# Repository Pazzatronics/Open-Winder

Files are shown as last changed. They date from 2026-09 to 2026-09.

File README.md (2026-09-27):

# Open Winder

A DIY guitar pickup coil winder built around a Teensy 4.1: standalone touchscreen operation (planned), tension feedback via load cell, EEPROM/flash profile storage, and wind logging.

This repo is open source. Ready-made/printed components based on this design are also sold separately by [Pazzatronics](https://www.pazzatronics.com) — building it yourself from these files is always free and unrestricted under the terms below.

## Repo layout

```
firmware/       Teensy 4.1 sketch and any supporting libraries
hardware/
  fusion360/    Native Fusion 360 project files
  stl/          Print-ready STL files (all parts printed in PETG)
  step/         Exported STEP files (winder body, brackets, load-cell pulley, etc.)
  wiring/       Pinout tables, wiring notes, and open_winder_wiring.csv
  bom.md        Bill of materials with sourcing links
docs/           Bug write-ups, firmware architecture notes, command protocol
```

## Hardware stack

| Part | Component |
|---|---|
| MCU | Teensy 4.1 (3.3 V logic) |
| Stepper driver | DM542T |
| Winder motor | 23HS45-4204S (4.2 A, 3 Nm) |
| PSU | LRS-350-24 (24 V) |
| Load cell | HX711 amplifier + parallel-beam 1 kg load cell |
| Flash storage | Winbond W25Q64JV (QSPI, LittleFS) |
| Level shifting | 74AHCT125 (Teensy 3.3 V → driver 5 V logic) |

Full sourcing and links: [`hardware/bom.md`](hardware/bom.md)

## Status

This is an active, evolving hobby project — see [`docs/bugs-and-fixes.md`](docs/bugs-and-fixes.md) for known firmware issues and their fix status, and [`docs/rebuild-architecture.md`](docs/rebuild-architecture.md) for the planned ISR-based firmware rewrite.

## License

- **Firmware** (`firmware/`): [MIT](LICENSE-FIRMWARE) — do whatever you want with it, attribution appreciated.
- **Hardware** (`hardware/`): [CERN-OHL-S v2](LICENSE-HARDWARE) — you're free to build, modify, and even sell things made from these designs, but if you distribute a modified version of the hardware design itself, you need to share those modifications under the same license.

Questions about licensing or commercial use beyond what these licenses already allow: open an issue or reach out directly.

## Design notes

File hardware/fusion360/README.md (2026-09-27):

# Fusion 360 Files

Native Fusion 360 project files for the Open Winder assembly go here (.f3d exports, or a note pointing to the hosted Fusion 360 project if you'd rather link than commit binary CAD files directly).

Current assembly includes:
- Winder body/frame
- Load cell pulley (three-wheel over/under/over routing, 30° strand angle, 1:1 force ratio)
- Laser module mount (Ø9 x 33 mm housing, emitting face at world origin, beam along +Z)

See ../step/ for exported STEP files if you want a CAD-tool-agnostic format alongside the native files.

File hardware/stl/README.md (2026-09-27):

# Open Winder STL Files

Print-ready STLs for the Open Winder body, clamps, motor brackets, limit-switch housings and tension-sensor housing.

All parts are printed in **PETG**.

| File | Part |
|---|---|
| Housing_1.stl | Main housing |
| Top_Clamp_1.stl / Bottom_Clamp_1.stl | Clamps |
| Motor_Bracket_Front_Top_Spindle_1.stl / Motor_Bracket_Rear_Top_Spindle_1.stl | Spindle (winder) motor brackets |
| Motor_Bracket_Front_Top_Traverse_1.stl / Motor_Bracket_Rear_Top_Traverse_1.stl | Traverse motor brackets |
| Top_Limit_Housing_1.stl / Bottom_Limit_Housing_1.stl | Limit-switch housings |
| Tension_Sensor_Housing_1.stl | Load-cell (tension sensor) housing |

Editable CAD is in `../step/` (STEP) and `../fusion360/` (Fusion 360).

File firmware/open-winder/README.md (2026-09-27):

# Open Winder Firmware

Target: Teensy 4.1, built with Arduino IDE + Teensyduino.

`open_winder_public.ino` is the current public firmware (based on rev 2026-09-16b).

## Before your first run

- Set `TRAV_LEAD_UM_PER_REV` to your traverse lead screw (in microns per revolution).
- Set `WINDER_STEPS_PER_REV` and `TRAV_STEPS_PER_REV` to match the DM542T DIP switches on each drive (the defaults assume 400 steps/rev: SW5 OFF, SW6 ON, SW7 ON, SW8 ON).
- The `defcal` window constants (`DEFAULT_PROFILE_*`, `DEFAULT_CAL_OFF*`) came from the reference machine. Run `cal`, set your bounds with `jogt`/`jogb`/`savet`/`saveb`, send `donecal`, then `stat`, and copy `DEF_TOP_INSET_STEPS` / `DEF_BOTTOM_INSET_STEPS` into the sketch.

## Running a wind

Commands are typed over USB serial at 115200 baud. Send `help` for the full list. A minimal job:

```
dir cw
rpm 500
turns 8000
space 1.0
defcal
start
```

Wiring for every pin used here is in `../../hardware/wiring/open_winder_wiring.csv`.

See `../../docs/bugs-and-fixes.md` for known issues and `../../docs/rebuild-architecture.md` for the planned ISR-based rewrite.

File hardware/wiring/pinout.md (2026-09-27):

# Pinout & Wiring Notes

Bench-verified on the as-built machine, September 2026.

## Limit switches

| Pin | Function | Notes |
|---|---|---|
| 7 | BOTTOM limit | NC switch: idle LOW, tripped HIGH |
| 8 | TOP limit | NC switch: idle LOW, tripped HIGH |

Traverse direction: **CW = toward TOP** (`TRAVERSE_DIR_INVERT = false` is correct for this build).

## Load cell (HX711)

| Pin | Function |
|---|---|
| 30 | DT (data) |
| 31 | SCK (clock) |

Bit-banged GPIO, not a hardware SPI/I2C peripheral. Originally 22/23 in early firmware — moved to 30/31 in the current build.

## Winder motor coil pairing (23HS45-4204S)

Verified with a multimeter — **do not assume by wire color convention**:

- Coil A: black + green
- Coil B: red + blue

(The usual convention of black/red as one pair and blue/green as the other does **not** hold for this motor.)

## Stepper driver (DM542T)

- DIP switches set for **4.20 A peak**, **1600 microsteps/rev** at the driver
- Bench-verified actual winder motion: 1600 pulses = 4.000 revolutions → **400 steps/rev**, corresponding to microstep setting 2 (SW5 OFF / SW6 ON / SW7 ON / SW8 ON)
- Traverse axis steps/rev not yet verified — its DIP switches differ from the winder axis

## Logic level shifting

Teensy 4.1 I/O is 3.3 V; DM542T STEP/DIR inputs are spec'd 4–5 V. A 74AHCT125 buffer is planned/used on these lines. Hardware margin note: DIR setup time measured at exactly the 5 µs minimum — suspected root cause of traverse drift at direction reversals (see `docs/bugs-and-fixes.md`).

## Safety / interlocks

- Run-permit and snag-fault inputs are **not wired** in the current build
- E-stop is the LRS-350 power switch
- Snag-detection code is retained in firmware behind a compile flag for future use

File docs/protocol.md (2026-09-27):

# Command Protocol

ASCII text protocol over USB serial and Serial1, unchanged across the patched firmware and the planned rebuild.

> **Status:** partial — this file has the commands referenced so far in project notes. Fill in the rest of the command set (full syntax, arguments, and responses) as you formalize it. Consider this a living reference, not a spec written up front.

## Known commands

| Command | Purpose |
|---|---|
| `reset` | Reset run state; preserves tare |
| `resetall` | Full reset — re-seeds ISR timing state, restores motion after a dead-motor freeze |
| `driftcomp <steps> <turns>` | Manually set learned per-reversal traverse drift correction |
| `saveprofile` | Save current profile/preset/tension calibration to EEPROM |

## Reporting

| Report | Trigger |
|---|---|
| `RECAL_DRIFT` | Emitted at every auto-recalibration |
| `STATUS` | Periodic telemetry (target: fixed 10 Hz, gated by `availableForWrite()`) |
| `FAULT_STALL` | Raised when hall-index-derived RPM/turn count disagrees with commanded step count |

## Turn-boundary concepts

- **Chaos** — pattern variation applied to traverse spacing
- **Mid** — mid-point traverse behavior
- **Taps** — intermediate turn-count targets within a wind
- **Total** — final target turn count for the wind

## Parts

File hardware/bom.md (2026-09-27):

# Bill of Materials

Links below are **search queries**, not pinned product listings — sellers, prices, and ASINs on generic electronics parts (steppers, drivers, PSUs) turn over too often for a fixed link to stay reliable. Click through, compare current listings, and confirm specs match the row before buying.

| Qty | Part | Key specs | Source | Notes |
|---|---|---|---|---|
| 1 | Teensy 4.1 | ARM Cortex-M7 @ 600 MHz, 3.3 V logic | **[pjrc.com](https://www.pjrc.com/store/teensy41.html)** (buy direct — see note) | Third-party Amazon listings routinely mark this up over PJRC's own price; PJRC is the manufacturer |
| 1 | Stepper driver | DM542T, 4–5 V input, up to 50 V / 4.2 A | [Amazon search](https://www.amazon.com/s?k=DM542T+stepper+driver) | DIP-configured for 4.20 A peak, 1600 µsteps in this build |
| 1 | Winder motor | NEMA23 stepper, 23HS45-4204S, 4.2 A, 3 Nm, 0.88 Ω, 3.4 mH | [Amazon search](https://www.amazon.com/s?k=23HS45-4204S+nema+23+stepper+motor) | Coil pairing bench-verified: black+green = coil 1, red+blue = coil 2 (not the usual black/red + blue/green convention) |
| 1 | Power supply | LRS-350-24, 24 V rail, 350 W enclosed switching PSU | [Amazon search](https://www.amazon.com/s?k=LRS-350-24+power+supply) | Confirmed 24 V variant (not 36/48 V) |
| 1 | Load cell + amp | HX711 amplifier board + parallel-beam 1 kg load cell | [Amazon search](https://www.amazon.com/s?k=HX711+load+cell+1kg+parallel+beam) | Bit-banged GPIO; pins DT=30, SCK=31 in this build |
| 1 | Flash storage | Winbond W25Q64JV, QSPI NOR flash, 64 Mbit | [Amazon search](https://www.amazon.com/s?k=W25Q64JV+flash+chip) | For wind-log storage via LittleFS |
| 1+ | Level shifter | 74AHCT125, quad buffer/line driver | [Amazon search](https://www.amazon.com/s?k=74AHCT125) | Needed on STEP/DIR lines: Teensy is 3.3 V, DM542T inputs are spec'd 4–5 V |
| — | Limit switches | Mechanical/optical, NC configuration | [Amazon search](https://www.amazon.com/s?k=limit+switch+NC) | Bench-verified: pin 7 = BOTTOM, pin 8 = TOP; idle LOW, tripped HIGH |
| — | Fasteners / misc | — | — | See Fusion 360 assembly BOM export for exact hardware call-outs |

## Not yet finalized

- Touchscreen: leaning ESP32-S3 + capacitive LCD (LVGL over UART) vs. Nextion NX4827P043-011C vs. Teensy-driven SPI TFT — see `docs/rebuild-architecture.md`
- Laser/LED module for the optical sub-project — see project notes

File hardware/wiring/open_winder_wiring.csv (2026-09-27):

ID | Subsystem | From Component | From Pin / Terminal | To Component | To Pin / Terminal | Signal | Firmware Reference | Notes
P1 | Mains power | AC mains line | L | LRS-350 PSU | L | AC line | n/a | Mains wiring: switched and fused. The LRS-350 power switch is the E-stop on the reference build (no firmware run-permit fitted).
P2 | Mains power | AC mains neutral | N | LRS-350 PSU | N | AC neutral | n/a
P3 | Mains power | AC mains earth | PE | LRS-350 PSU | FG (earth) | Protective earth | n/a | Also bond the machine frame to earth.
P4 | DC power | LRS-350 PSU | +V (terminal 1) | Winder DM542T | +V | Motor supply + | n/a | DM542T accepts 20-50 VDC including back-EMF. Run each drive from its own PSU terminal pair (not daisy-chained) per the DM542T manual.
P5 | DC power | LRS-350 PSU | -V (terminal 1) | Winder DM542T | GND | Motor supply return | n/a
P6 | DC power | LRS-350 PSU | +V (terminal 2) | Traverse DM542T | +V | Motor supply + | n/a | Separate terminal from P4.
P7 | DC power | LRS-350 PSU | -V (terminal 2) | Traverse DM542T | GND | Motor supply return | n/a | Separate terminal from P5.
P8 | Logic power / comms | Teensy 4.1 | Micro-USB | Host computer | USB | 5 V power + USB serial | SERIAL_BAUD = 115200 | All commands are typed over this port (Serial Monitor). Teensy 3.3 V rail also powers the HX711.
W1 | Winder drive signals | Teensy 4.1 | Pin 2 | Winder DM542T | PUL+ | STEP | PIN_WINDER_STEP | Active on rising edge; 5 us pulse (STEP_PULSE_US). Common-cathode wiring: Teensy sources current into PUL+.
W2 | Winder drive signals | Teensy 4.1 | GND | Winder DM542T | PUL- | STEP return | n/a
W3 | Winder drive signals | Teensy 4.1 | Pin 3 | Winder DM542T | DIR+ | DIR | PIN_WINDER_DIR | HIGH = CW with WINDER_DIR_INVERT = false. 5 us setup before first step (DIR_SETUP_US).
W4 | Winder drive signals | Teensy 4.1 | GND | Winder DM542T | DIR- | DIR return | n/a
W5 | Winder drive signals | Winder DM542T | ENA+ / ENA- | (none) | Not connected | Enable | not used | Left unconnected = drive always enabled (DM542T default).
W6 | Winder motor | Winder DM542T | A+ | Winder motor 23HS45-4204S | Black lead | Phase A+ | n/a | Black + Green are one coil. Confirm pairs with a meter before powering.
W7 | Winder motor | Winder DM542T | A- | Winder motor 23HS45-4204S | Green lead | Phase A- | n/a
W8 | Winder motor | Winder DM542T | B+ | Winder motor 23HS45-4204S | Red lead | Phase B+ | n/a | Red + Blue are the other coil.
W9 | Winder motor | Winder DM542T | B- | Winder motor 23HS45-4204S | Blue lead | Phase B- | n/a | Never plug or unplug motor leads with the drive powered.
T1 | Traverse drive signals | Teensy 4.1 | Pin 4 | Traverse DM542T | PUL+ | STEP | PIN_TRAV_STEP | Active on rising edge; 5 us pulse.
T2 | Traverse drive signals | Teensy 4.1 | GND | Traverse DM542T | PUL- | STEP return | n/a
T3 | Traverse drive signals | Teensy 4.1 | Pin 5 | Traverse DM542T | DIR+ | DIR | PIN_TRAV_DIR | HIGH = carriage toward TOP with TRAVERSE_DIR_INVERT = false. 60 us settle on each reversal (TRAV_REVERSAL_DIR_SETTLE_US).
T4 | Traverse drive signals | Teensy 4.1 | GND | Traverse DM542T | DIR- | DIR return | n/a
T5 | Traverse drive signals | Traverse DM542T | ENA+ / ENA- | (none) | Not connected | Enable | not used | Left unconnected = drive always enabled.
T6 | Traverse motor | Traverse DM542T | A+ | Traverse stepper motor | Black lead | Phase A+ | n/a | Colours shown are for a 23HS45-4204S; use your motor's own datasheet if different.
T7 | Traverse motor | Traverse DM542T | A- | Traverse stepper motor | Green lead | Phase A- | n/a
T8 | Traverse motor | Traverse DM542T | B+ | Traverse stepper motor | Red lead | Phase B+ | n/a
T9 | Traverse motor | Traverse DM542T | B- | Traverse stepper motor | Blue lead | Phase B- | n/a
L1 | Limit switches | Teensy 4.1 | Pin 7 | BOTTOM limit switch | COM | BOTTOM limit | PIN_BOTTOM_LIMIT | INPUT_PULLUP; firmware reads HIGH = tripped. 5 ms debounce (LIMIT_DEBOUNCE_US).
L2 | Limit switches | BOTTOM limit switch | NC | Teensy 4.1 | GND | BOTTOM limit return | n/a | Use the NORMALLY CLOSED contact: idle = closed to GND = LOW; pressed = open = HIGH. A broken wire also reads HIGH so it fails safe as tripped.
L3 | Limit switches | Teensy 4.1 | Pin 8 | TOP limit switch | COM | TOP limit | PIN_TOP_LIMIT | INPUT_PULLUP; firmware reads HIGH = tripped. 5 ms debounce.
L4 | Limit switches | TOP limit switch | NC | Teensy 4.1 | GND | TOP limit return | n/a | NC contact as for L2.
H1 | Tension (HX711) | Teensy 4.1 | 3.3V | HX711 board | VCC | Logic/analog supply | n/a | Must be 3.3 V (not 5 V) so DT never exceeds Teensy 4.1 pin limits. If the board has a separate VDD pin tie it to 3.3 V too.
H2 | Tension (HX711) | Teensy 4.1 | GND | HX711 board | GND | Ground | n/a
H3 | Tension (HX711) | Teensy 4.1 | Pin 30 | HX711 board | DT (DOUT) | Data out | PIN_HX711_DT | INPUT_PULLUP; LOW = conversion ready.
H4 | Tension (HX711) | Teensy 4.1 | Pin 31 | HX711 board | SCK (CLK) | Clock | PIN_HX711_SCK | Idles LOW; bit-banged at 500 ns (HX711_PULSE_NS). Held HIGH >60 us powers the HX711 down.
H5 | Tension (HX711) | HX711 board | E+ | Load cell | Red lead (typical) | Excitation + | n/a | Load cell colours vary by maker - check the label on your cell.
H6 | Tension (HX711) | HX711 board | E- | Load cell | Black lead (typical) | Excitation - | n/a
H7 | Tension (HX711) | HX711 board | A- | Load cell | White lead (typical) | Signal - | n/a | Channel A gain 128 is selected by firmware.
H8 | Tension (HX711) | HX711 board | A+ | Load cell | Green lead (typical) | Signal + | n/a | Polarity is not critical: zero + tare derives the sign from the reference mass so wire tension reads positive either way.
O1 | Optional safety (compiled out) | Teensy 4.1 | Pin 33 | Run-permit switch | Contact 1 | RUN PERMIT | PIN_RUN_PERMIT (HAS_RUN_PERMIT = 0) | Only if HAS_RUN_PERMIT set to 1. INPUT_PULLUP; LOW = run enabled. Leave unwired while the flag is 0.
O2 | Optional safety (compiled out) | Run-permit switch | Contact 2 | Teensy 4.1 | GND | RUN PERMIT return | n/a | Closed = enabled; opening it trips FAULT_FAILSAFE.
O3 | Optional safety (compiled out) | Teensy 4.1 | Pin 34 | Snag sensor | Output | SNAG | PIN_SNAG_FAULT (HAS_SNAG_FAULT = 0) | Only if HAS_SNAG_FAULT set to 1. INPUT_PULLUP; LOW = OK; HIGH trips FAULT_SNAG. Code comment suggests pin 32 as an alternative.
O4 | Optional safety (compiled out) | Snag sensor | GND / return | Teensy 4.1 | GND | SNAG return | n/a
C1 | Driver configuration (not a wire) | Winder DM542T | DIP SW5-SW8 | (setting) | SW5 OFF / SW6 ON / SW7 ON / SW8 ON | 400 steps/rev | WINDER_STEPS_PER_REV = 400 | Must match the constant or turn count and speed will be wrong.
C2 | Driver configuration (not a wire) | Traverse DM542T | DIP SW5-SW8 | (setting) | SW5 OFF / SW6 ON / SW7 ON / SW8 ON | 400 steps/rev | TRAV_STEPS_PER_REV = 400 | Must match the constant or traverse spacing will be wrong.
C3 | Driver configuration (not a wire) | Both DM542T | DIP SW1-SW4 | (setting) | Per DM542T manual | Current / standstill current | not set by firmware | Choose peak current for your motor and load using the DM542T current table.
C4 | Signal level note | Teensy 4.1 | Pins 2-5 | DM542T | PUL+ / DIR+ | 3.3 V logic | n/a | The DM542T manual specifies 4-5 V for a HIGH input. Direct 3.3 V drive works on the reference build but is below spec; a 5 V buffer such as a 74AHCT125 on pins 2-5 is the in-spec option.

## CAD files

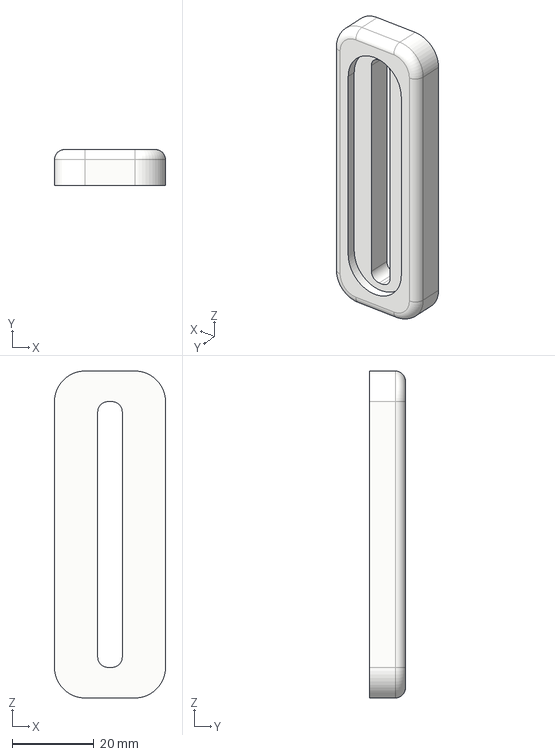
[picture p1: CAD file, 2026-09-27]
hardware/step/Top Clamp.step
27.2 x 8.81 x 80.0 mm

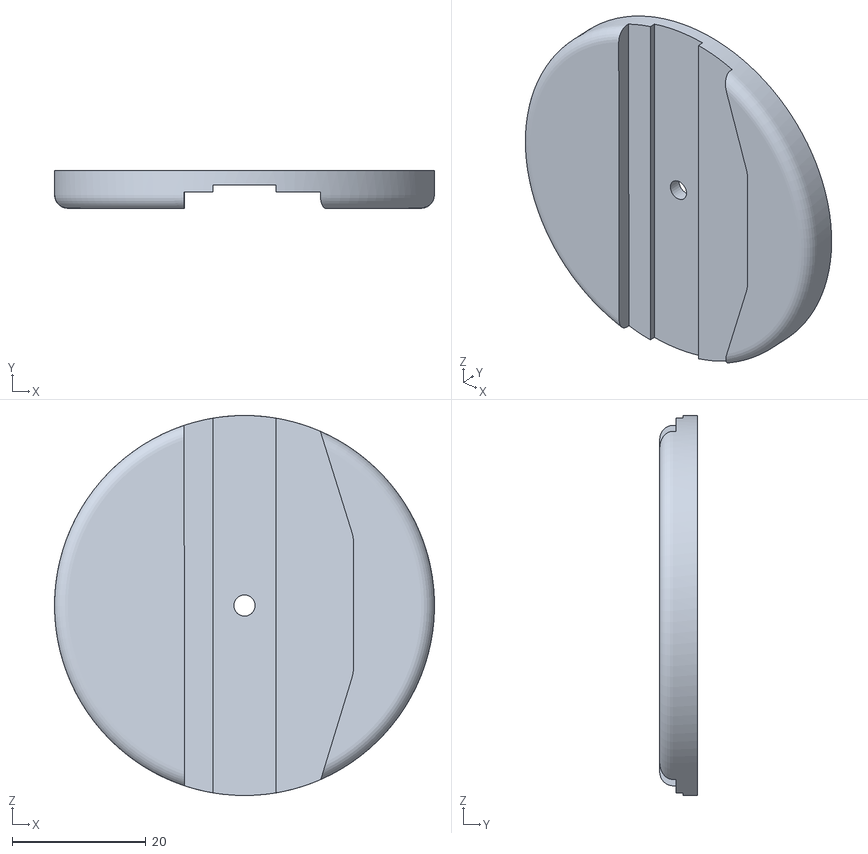
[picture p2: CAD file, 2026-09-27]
hardware/stl/Bottom_Clamp_1.stl
56.8 x 5.64 x 56.8

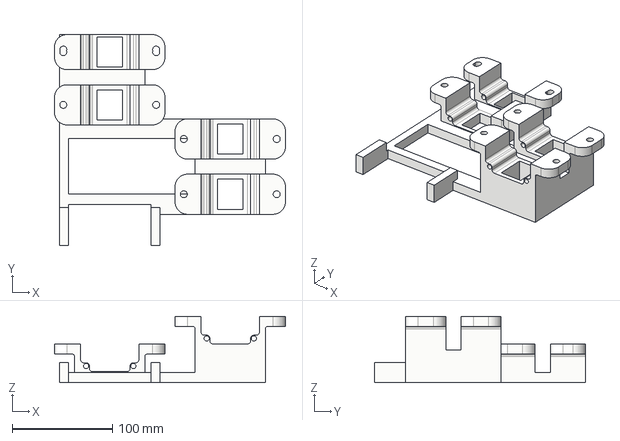
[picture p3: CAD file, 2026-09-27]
hardware/step/Housing.step
230.0 x 210.0 x 66.0 mm

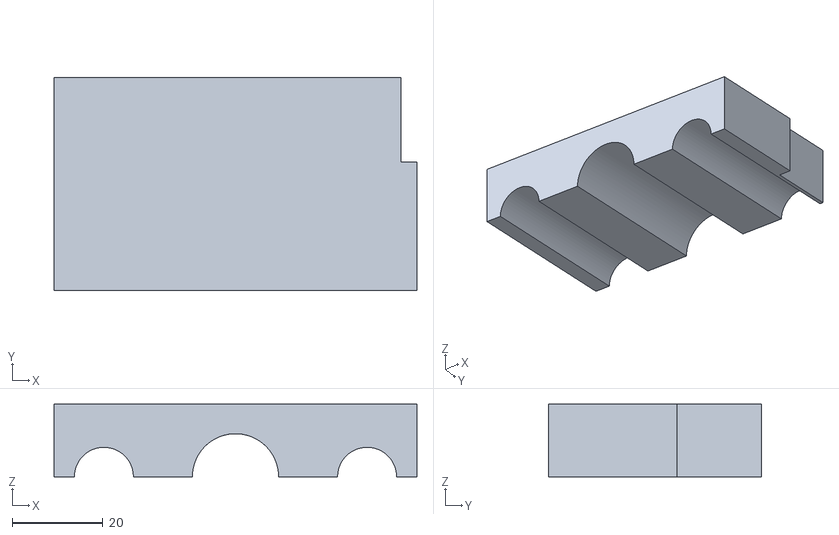
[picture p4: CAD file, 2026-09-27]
hardware/stl/Top_Limit_Housing_1.stl
80.0 x 47.0 x 16.0

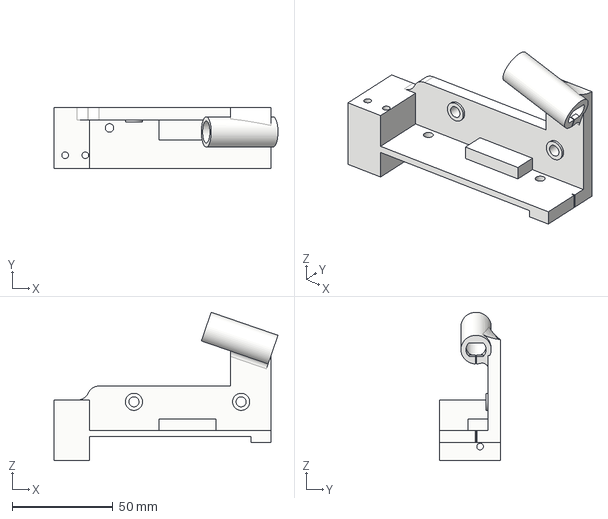
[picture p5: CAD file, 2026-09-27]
hardware/step/Tension Sensor Housing.step
111.0 x 30.0 x 73.5 mm

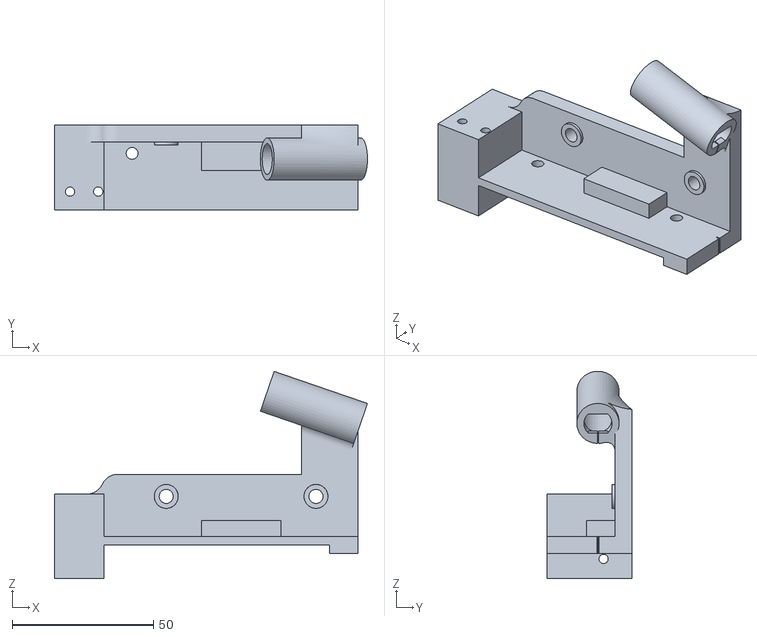
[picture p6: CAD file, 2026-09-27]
hardware/stl/Tension_Sensor_Housing_1.stl
111.0 x 30.0 x 73.5

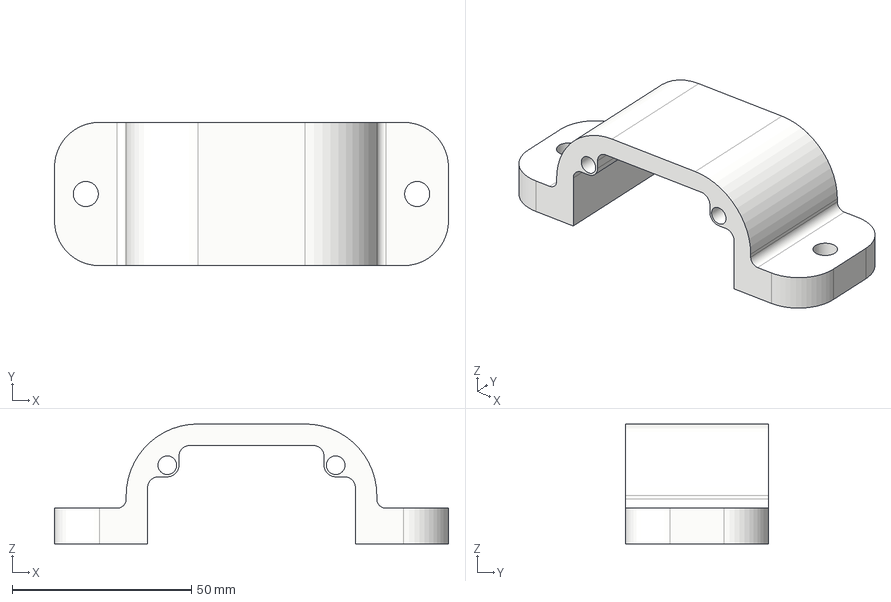
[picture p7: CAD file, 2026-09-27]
hardware/step/Motor Bracket Front Top Traverse.step
110.0 x 40.0 x 33.5 mm

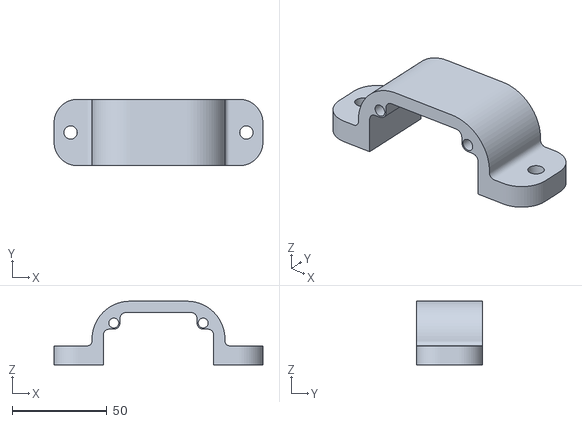
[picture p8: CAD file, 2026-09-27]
hardware/stl/Motor_Bracket_Rear_Top_Traverse_1.stl
110.0 x 35.0 x 33.5

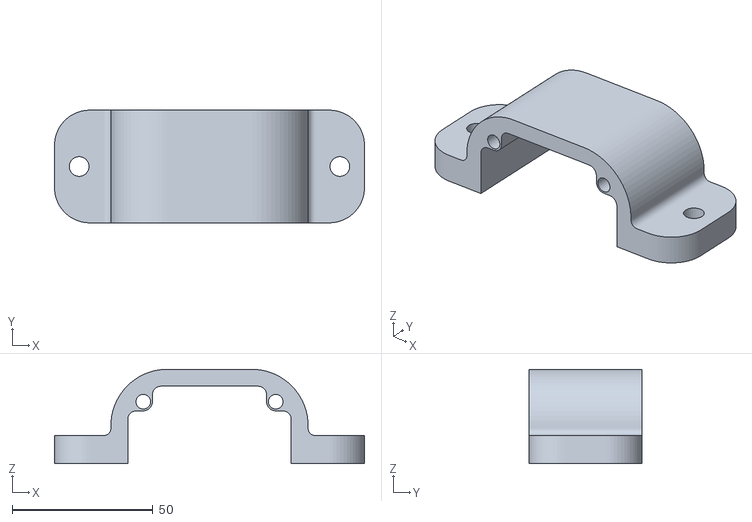
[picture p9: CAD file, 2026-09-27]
hardware/stl/Motor_Bracket_Front_Top_Traverse_1.stl
110.0 x 40.0 x 33.5

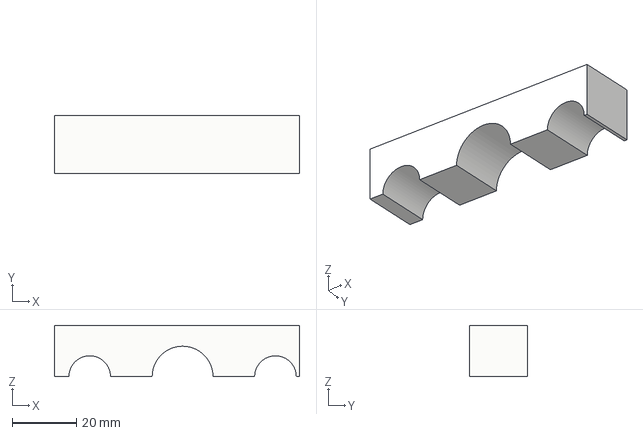
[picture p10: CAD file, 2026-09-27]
hardware/step/Bottom Limit Housing.step
76.5 x 18.0 x 16.0 mm

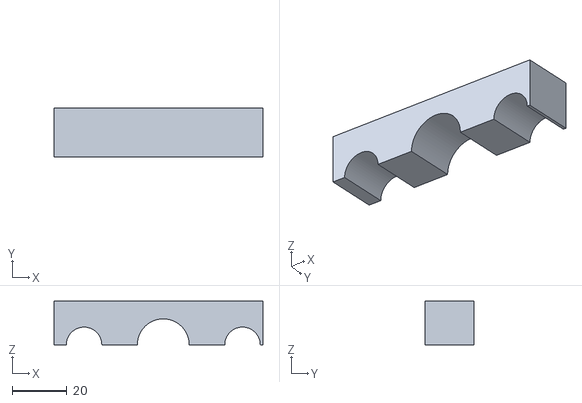
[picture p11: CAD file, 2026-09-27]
hardware/stl/Bottom_Limit_Housing_1.stl
76.5 x 18.0 x 16.0

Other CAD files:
hardware/step/Motor Bracket Front Bottom Traverse.step
hardware/step/Motor Bracket Front Top Spindle.step
hardware/stl/Motor_Bracket_Rear_Top_Spindle_1.stl
hardware/stl/Motor_Bracket_Front_Top_Spindle_1.stl
hardware/step/Top Limit Housing.step
hardware/stl/Top_Clamp_1.stl
hardware/step/Motor Bracket Rear Bottom Traverse.step
hardware/step/Bottom Clamp.step
hardware/step/Motor Bracket Front Bottom Spindle.step
hardware/step/Motor Bracket Rear Bottom Spindle.step
hardware/step/Motor Bracket Rear Top Spindle.step
hardware/step/Motor Bracket Rear Top Traverse.step
hardware/stl/Housing_1.stl

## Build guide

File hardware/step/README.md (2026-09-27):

# STEP Files

STEP (.step/.stp) exports of the winder body and mechanical assemblies -- CAD-tool-agnostic, viewable/editable in FreeCAD, SolidWorks, Onshape, etc. without a Fusion 360 license.

Keep filenames matching the corresponding Fusion 360 component name so the two stay easy to cross-reference.

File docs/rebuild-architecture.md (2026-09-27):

# Firmware Rebuild Architecture (planned, not yet coded)

The current machine runs the original firmware with surgical patches (see `bugs-and-fixes.md` — the dead-motor bug is fixed this way). A full rewrite was attempted once and failed on the machine, so the plan below is being implemented incrementally rather than as a single rewrite.

## PIT IntervalTimer ISR (step generation)

- Toggles winder STEP at 2× the step rate (one toggle = one edge; two toggles = one pulse)
- Traverse motion driven by a Bresenham-style accumulator: `acc += spacing; if (acc >= 16000) { pulse; acc -= 16000; }`
- Bounds/limit checks performed inside the ISR
- DIR line written one full ISR tick *before* the first step in a new direction — this is the fix for the traverse-drift root cause
- Position counted on the driver's active (rising) edge, not falling
- All arithmetic kept integer — avoids the float-precision issue described in `bugs-and-fixes.md`

## 1 kHz control tick

- Fixed-point milli-RPM ramp (replaces the lossy float accumulator)
- Spacing computed as soft-scale × chaos × mid factors
- Turn-boundary logic: chaos pattern, mid-point behavior, tap counting, auto-recalibration, total-turns stop
- Decel anticipation: begin slowing `RPM² / (120 × ramp)` turns before the target so taps/total land exactly on the number, not past it
- Stall detection

## `loop()` (non-timing-critical work only)

- USB and Serial1 command ports, same ASCII text protocol as today (see `protocol.md`)
- HX711 polling
- Telemetry via `snprintf`, gated by `availableForWrite()`, fixed at 10 Hz
- Logging to flash/SD
- Display updates

## Spindle hall index sensor (1 pulse/rev)

- Maintains the turn count of record and actual RPM independent of commanded step count
- Raises `FAULT_STALL` on mismatch: freezes the turn count and stops traverse
- Commanded step count is retained separately for traverse gearing
- Cross-checked against the ISR-driven count in the 1 kHz tick

## Storage

- EEPROM: profiles, presets, tension calibration — `saveprofile` command replaces the old DEFCAL-REBUILD-and-reflash workflow
- W25Q64 QSPI (LittleFS) or microSD: wind logs

## Traverse drift — diagnostics and correction hierarchy

Diagnostics to run **before** the rebuild lands, to further isolate the drift mechanism:
1. Print `HARD_TOP` / `HARD_BOTTOM` at every auto-recalibration
2. Add active bounds to `STATUS` output
3. Raise reversal DIR setup time to 50 µs to confirm the root-cause theory
4. Compare drift magnitude at 250 vs. 500 RPM

Correction approaches, in preferred order:
1. **Slotted-opto flag** on the traverse carriage — per-layer counter re-sync without stopping (preferred long-term fix)
2. **Quick re-home** to the bottom limit switch at taps/start/interval
3. **Learned `driftcomp`** per-reversal counter correction (`driftcomp <steps> <turns>`) as a fallback/interim measure

## Touchscreen (not yet started)

Options under consideration, in order of preference:
1. Separate ESP32-S3 + capacitive LCD running LVGL, communicating over UART using the existing command protocol
2. Nextion NX4827P043-011C over Serial1 — requires a 5 V external supply and a voltage divider on Nextion TX → Teensy RX, but plugs into the existing ASCII protocol with minimal Teensy-side changes
3. Last resort: Teensy-driven SPI TFT

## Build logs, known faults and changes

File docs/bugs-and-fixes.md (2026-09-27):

# Diagnosed Firmware Bugs

Four bugs were diagnosed against the original firmware. As of the current patched revision, the dead-motor bug is fixed on the running machine; the other three are slated for the ISR-based rebuild (see `rebuild-architecture.md`).

## 1. Dead motor after long pause — FIXED (patched, confirmed on machine)

`StepperAxis::update()` compared `(int32_t)(nowUs - nextStepUs) >= 0` to decide whether a step was due. `stopImmediate()` zeroed `intervalUs` but left `nextStepUs` frozen. Since `micros()` wraps every ~71.58 minutes, the signed difference goes negative for ~35.79 minutes after a wrap, silently halting pulses from both axes.

- **Field evidence:** turn count frozen at 4062, `rpm_now` ramping down from 471→208, `trav_steps` frozen, all other health signals reporting normal.
- **Confirmation test:** `resetall` (calls `begin()`, reseeding `nextStepUs`) restored motion immediately.
- **Self-heals** after ~36 minutes even without intervention.
- **Fix:** idle-freeze `micros()`-wrap re-seed patch, shipped in the 2026-09-16 firmware revision.

## 2. High-RPM stall — OPEN (rebuild required)

Step pulses are generated by polling `micros()` inside `loop()`. Several things can block that loop for 200–600 µs at a time:

- Telemetry bursts
- ~55 µs blocking HX711 reads
- Blocking traverse pulses issued inside the winder's own step handler
- `String` parsing that touches the heap/stack

At 1000 RPM (26.7 kHz step rate → 37.5 µs/step budget), any of these is fatal — the firmware is open-loop, so a stall doesn't halt anything visibly; turns and traverse position keep incrementing as if nothing happened.

- **Fix (planned):** move step generation to a PIT `IntervalTimer` ISR, decoupled from `loop()` entirely. See `rebuild-architecture.md`.

## 3. Traverse drift — OPEN (rebuild required)

Carriage drifts 1–2 mm toward the top per ~2000 turns; currently reset by periodic recalibration.

**Root cause:** DIR setup time is exactly at the 5 µs minimum at each reversal, driven through a 3.3 V opto. The first step pulse after a reversal executes in the *old* direction before the new DIR value is honored, at ~20 µm per affected reversal, always in the same sense. This predicts drift of roughly `20/W` mm per 2000 turns, where W is the winding band width in mm.

Minor contributing factors:
- `update()` counts position on the falling edge of the step pulse
- `stopImmediate()` drops an already-accepted pulse

- **Fix (planned):** 74AHCT125 buffer + writing DIR one full ISR tick before the first step + counting position on the driver's active edge. See drift diagnostics/correction hierarchy in `rebuild-architecture.md`.

## 4. Float ramp precision loss — OPEN (rebuild required)

Field log shows an effective ramp rate of ~65 rpm/s against a configured 75 rpm/s. Repeatedly adding `75e-6` to a `float` accumulator near 471 loses precision at that magnitude.

- **Fix (planned):** replace with a milli-RPM fixed-point ramp evaluated in the 1 kHz control tick.

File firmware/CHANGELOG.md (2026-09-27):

# Firmware Changelog

## Public release (from 2026-09-16b)
- Product-specific winding presets removed; jobs are set up with dir / rpm / turns / space and optional taps
- File renamed to `open_winder_public.ino`
- Wiring table added: `../hardware/wiring/open_winder_wiring.csv`

## 2026-09-16b
- Ported August-audit fixes: stop-over-pause priority, decel anticipation (taps/total land exactly on target), single pending tap, chained-fault guard, jog limit stop, zero/tare refused while moving, spin ramps, in-flight step counted, tension baseline decay fix, 500 ns HX711 pulses, watchdog optional (off by default)
- Not yet confirmed on the machine. Note: taps/total now land on the exact number rather than ~28 turns past it.

## 2026-09-16
- Idle-freeze micros()-wrap re-seed fix (dead-motor bug -- see ../docs/bugs-and-fixes.md)
- Winder set to 400 steps/rev (bench-verified, was assumed 1600)
- HX711 moved to pins 30/31 (was 22/23)
- Run-permit and snag-fault checks compiled out (not wired on this build)
- reset now preserves tare
- RECAL_DRIFT report added at every auto-recalibration
- driftcomp <steps> <turns> command added
- Confirmed working on the machine ("works well")

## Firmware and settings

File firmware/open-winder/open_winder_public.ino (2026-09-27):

/*
  Open Winder - Guitar Pickup Coil Winder Firmware
  Teensy 4.1

  Public release (derived from rev 2026-09-16b)
  ---------------------------------------------
  - Product-specific winding presets removed. Set up a job with
    dir / rpm / turns / space (and optional taps), then cal or defcal, then start.
  - The defcal window (DEFAULT_PROFILE_* and DEFAULT_CAL_OFF* constants below) came
    from the reference machine. For your machine: run cal, jog + savet / saveb,
    donecal, then stat, and copy DEF_TOP_INSET_STEPS / DEF_BOTTOM_INSET_STEPS into
    DEFAULT_PROFILE_TOP_INSET_STEPS / DEFAULT_PROFILE_BOTTOM_INSET_STEPS.
  - Set TRAV_LEAD_UM_PER_REV and both *_STEPS_PER_REV to match your hardware and
    driver DIP switches before the first run.
  - See the accompanying wiring CSV for pin-to-terminal connections.

  Revision 2026-09-16b (August audit fixes ported onto the proven 09-16 build)
  ---------------------------------------------------------------------------
  - Stop outranks pause; stale stop/pause requests are cleared on resume, so a stop
    sent during a pause decel no longer terminates the run at the next tap.
  - Resume re-arms a pending auto recal instead of leaving it stuck until the next stop.
  - Taps and the total-turn stop anticipate the ramp-down (rpm^2 / (120*ramp) turns) so
    the wind lands ON the target instead of ~28 turns past it at 500 rpm / 75 rpm/s.
  - Only one tap can be pending at a time (second tap during one decel no longer
    overwrites the first).
  - Chained faults (a second fault while already faulted) no longer overwrite the saved
    resume context.
  - ack restarts a calibration that a fault interrupted (auto recal, or a defcal/cal from
    a paused run) so the saved run can still be restored instead of stranding it.
  - Manual cal started from PAUSED_AUTO/TAP_PAUSE returns to the paused run after donecal
    (traverse position restored) instead of stranding it in READY.
  - CAL_JOG: jogging into a limit switch stops the traverse.
  - nudget/nudgeb abort on permit/snag (when those inputs are fitted).
  - zero/tare rejected while the machine is moving (they block for up to 3 s).
  - spin ramps to speed instead of commanding full step rate in one jump (and loop() no
    longer re-applies full RPM every pass, which was defeating the ramp).
  - StepperAxis: in-flight step counted on stopImmediate (was dropped: 10 um per hard
    stop), step direction latched at the rising edge so a late DIR change cannot miscount,
    position counts in LOGICAL direction so a DIR_INVERT flip cannot desync cal vs wind,
    begin() zeroes positionSteps.
  - Tension baseline: decay can no longer truncate to zero (slow tension drift no longer
    trips a false FAULT_TENSION) and the rise is slew-limited so one spike cannot inflate
    the fault threshold.
  - HX711 bit-bang pulses shortened to 500 ns (halves the per-sample blocking time).
  - Optional hardware watchdog (USE_WATCHDOG, off by default).
  - Fault/status lines label tension as raw counts until zero+tare are done.

  Revision 2026-09-16 (bench-verified hardware + idle-freeze fix)
  ---------------------------------------------------------------
  - WINDER_STEPS_PER_REV 1600 -> 400. Bench: 1600 pulses = 4.000 rev, 400 = 1 rev.
    Winder DM542: SW5 OFF, SW6 ON, SW7 ON, SW8 ON (400 steps/rev). No DIP change needed.
  - TRAV_STEPS_PER_REV stays 400 and REQUIRES the traverse DM542 at 400 steps/rev:
    SW5 OFF, SW6 ON, SW7 ON, SW8 ON. Bench found it at 1600 (SW6 OFF) -> flip SW6 ON.
    A static_assert now refuses to build if the step size is not a whole number of microns.
  - HX711 moved to pins 30 (DT) / 31 (SCK).
  - Run permit / snag fault compiled out (HAS_RUN_PERMIT / HAS_SNAG_FAULT = 0). Code kept.
  - Idle-freeze fix: StepperAxis re-seeds nextStepUs/pulseEndUs when an axis wakes from
    stopped, and update() resyncs a stale timestamp. Cause of the old bug: micros() wraps
    every 71.6 min; the signed (now - nextStepUs) compare went negative ~35.8 min after a
    stop, so resume/pause "worked" but no pulses came out until resetall re-seeded it.
  - Traverse reversal: DIR gets TRAV_REVERSAL_DIR_SETTLE_US (60 us) only when the direction
    actually changes; normal steps keep the 5 us setup. Prime suspect for the upward drift.
  - RECAL_DRIFT line at every auto recal (and defcal/cal from a paused run): counter error
    at each hard switch since the previous cal, plus a ready-to-type driftcomp suggestion.
  - driftcomp <steps> <turns>: gradual counter correction, <steps> spread evenly over every
    <turns> turns. Positive = the wind drifts toward TOP. driftcompoff disables.
  - reset: same as resetall but keeps the HX711 zero + tare calibration.
  - STATUS line adds act_top / act_bot (active bounds) so drift can be assessed from logs.
  - defcal banner is printed from the live constants (it used to hardcode stale numbers).
  - DEFAULT_SPACE_UM comment corrected: 1000 um = 1.000 mm (value unchanged).

  Earlier notes (retained)
  ------------------------
  4 mm/rev traverse screw update:
  - Traverse screw changed from 2.000 mm/rev to 4.000 mm/rev
  - Traverse step size changed from 0.005 mm/step to 0.010 mm/step
  - Calibration/jog direct traverse RPMs were halved to preserve the old linear travel speed
  - Nudge step delay was doubled to preserve the old nudge linear speed
  - Winding traverse spacing math remains in micrometers, so spacing commands stay in mm

  Turn-count fix applied:
  - loop() now captures winder.update(nowUs) return value
  - handleWinderStepEvents() counts one commanded step per event
  - no dependency on winder.positionSteps delta for turn counting

  Entropy update:
  - true entropy is gathered only at setup(), start, resume, and calibration start
  - no periodic reseeding while running
  - chaos RNG state is then held constant until the next setup/start/resume/calibration

  Calibrated tension update:
  - HX711 zero is captured only by the zero command with no reference mass applied
  - tare <grams> is captured only when the known reference mass is applied
  - reference mass is treated as negative force because it pulls opposite wire tension
  - wire tension is reported positive in calibrated grams-force
  - plotter defaults on and prints Min1s_g, Max1s_g, Avg3s_g

  Tension-drop fault update:
  - Fault recovery rule: any fault that interrupts an active/paused auto wind clears to PAUSED_AUTO with ack, so resume continues the same run
  - While RUNNING_AUTO, a learned tension baseline is tracked in calibrated grams-force
  - If force drops sharply below the adaptive threshold and stays low for 20 turns, machine enters FAULT_TENSION
  - This avoids a fixed low-grams cutoff so lighter winds are less likely to false-trigger
*/

#include <Arduino.h>
#include <Entropy.h>
#include <limits.h>

// -----------------------------------------------------------------------------
// Optional safety inputs
// -----------------------------------------------------------------------------
// Neither is wired on the reference machine: the power-supply switch is the E-stop.
// With a flag at 0 the pin is never read. (An unwired INPUT_PULLUP pin reads HIGH,
// which the fault logic treats as tripped, and the machine would sit in
// FAULT_FAILSAFE / FAULT_SNAG from boot.) Set to 1 and wire the pin to use it.
#define HAS_RUN_PERMIT 0
#define HAS_SNAG_FAULT 0

// Hardware watchdog (Teensy 4.1 core, Watchdog_t4.h - no extra library). If loop() ever
// wedges for more than WDT_TIMEOUT_S the chip reboots, which drops all step pulses.
// Off by default; set to 1 to enable. Blocking paths (tare, nudge) feed it themselves.
// NOTE: no function definitions may appear above the enum/struct declarations
// below. The Arduino IDE injects auto-generated prototypes at the first function
// it finds, and those prototypes reference MachineState/TraverseDir.
#define USE_WATCHDOG 0
#if USE_WATCHDOG
#include "Watchdog_t4.h"
static constexpr uint32_t WDT_TIMEOUT_S = 10;
WDT_T4<WDT1> wdt;
#endif

// -----------------------------------------------------------------------------
// Pins
// -----------------------------------------------------------------------------
static constexpr uint8_t PIN_WINDER_STEP   = 2;
static constexpr uint8_t PIN_WINDER_DIR    = 3;
static constexpr uint8_t PIN_TRAV_STEP     = 4;
static constexpr uint8_t PIN_TRAV_DIR      = 5;

static constexpr uint8_t PIN_BOTTOM_LIMIT  = 7;   // right / bottom  (bench-verified)
static constexpr uint8_t PIN_TOP_LIMIT     = 8;   // left / top      (bench-verified)

static constexpr uint8_t PIN_RUN_PERMIT    = 33;  // LOW = enabled   (only read if HAS_RUN_PERMIT)
static constexpr uint8_t PIN_SNAG_FAULT    = 34;  // LOW = OK        (only read if HAS_SNAG_FAULT; use 32 if wired later)

// HX711 tension/load-cell reader
// Uses ordinary digital GPIO, not UART/SPI/I2C. HX711 VCC must be 3.3 V.
static constexpr uint8_t PIN_HX711_DT      = 30;  // HX711 DT/DOUT   (was 22)
static constexpr uint8_t PIN_HX711_SCK     = 31;  // HX711 SCK/CLK   (was 23)

static constexpr bool WINDER_DIR_INVERT   = false;  // HIGH = CW (bench-verified)
static constexpr bool TRAVERSE_DIR_INVERT = false;  // HIGH = toward TOP (bench-verified)

// -----------------------------------------------------------------------------
// Timing
// -----------------------------------------------------------------------------
static constexpr uint32_t SERIAL_BAUD        = 115200;
static constexpr uint32_t STEP_PULSE_US      = 5;
static constexpr uint32_t DIR_SETUP_US       = 5;
static constexpr uint32_t STATUS_INTERVAL_MS = 1000;
static constexpr uint32_t LIMIT_DEBOUNCE_US  = 5000;  // reject EMI/bounce spikes during motion

// Extra DIR settle used only when the traverse actually reverses direction while winding.
// The driver's 5 us minimum assumes 4-5 V drive; the Teensy gives 3.3 V and the optocoupler
// turns off slower than it turns on. Paid once per stroke, so it costs nothing at speed.
static constexpr uint32_t TRAV_REVERSAL_DIR_SETTLE_US = 60;

// Tension logging / plotting
// HX711 sample rate is set by the board RATE pin/jumper. This code reads only when ready.
// Serial Plotter line is emitted once per second as a max-over-window value.
static constexpr uint32_t TENSION_WINDOW_MS = 1000;
static constexpr uint32_t TENSION_STALE_MS  = 2000;
static constexpr uint16_t TENSION_CAL_SAMPLES = 16;
static constexpr uint32_t HX711_PULSE_NS = 500;  // >= 200 ns per HX711 datasheet; halves blocking vs 1 us pulses

// Tension-drop fault detection
// Fault only runs during RUNNING_AUTO and only after zero + tare calibration.
// It uses a learned baseline so low-tension winds are not judged by the same fixed cutoff as tight winds.
static constexpr uint32_t TENSION_DROP_CONFIRM_TURNS = 20;
static constexpr long     TENSION_DROP_BASELINE_MIN_G = 8;      // do not arm until normal running tension has reached this
static constexpr uint8_t  TENSION_DROP_KEEP_PCT = 55;           // fault candidate if force <= baseline * 55%
static constexpr uint32_t TENSION_DROP_IGNORE_START_TURNS = 5;  // ignore first few turns after start/resume

// -----------------------------------------------------------------------------
// Mechanics
// -----------------------------------------------------------------------------
// Traverse DM542 must be set to 400 steps/rev: SW5 OFF, SW6 ON, SW7 ON, SW8 ON.
static constexpr int32_t TRAV_STEPS_PER_REV   = 400;
static constexpr int32_t TRAV_LEAD_UM_PER_REV = 4000;  // 4.000 mm / rev lead screw
static constexpr int32_t TRAV_STEP_UM         = TRAV_LEAD_UM_PER_REV / TRAV_STEPS_PER_REV;  // 10 um = 0.010 mm / step
static_assert(TRAV_LEAD_UM_PER_REV % TRAV_STEPS_PER_REV == 0,
              "TRAV_STEP_UM must be a whole number of microns (1600 steps/rev would give 2.5 um and silently truncate)");
// Winder DM542 is set to 400 steps/rev: SW5 OFF, SW6 ON, SW7 ON, SW8 ON (bench-verified 2026-09-16).
static constexpr int32_t WINDER_STEPS_PER_REV = 400;

// -----------------------------------------------------------------------------
// Defaults
// -----------------------------------------------------------------------------
static constexpr uint32_t MIN_RPM = 1;
static constexpr uint32_t MAX_RPM = 1500;

static constexpr uint32_t NUDGE_STEP_DELAY_US = 6000;  // doubled for 4 mm/rev screw; same linear nudge speed as old 2 mm/rev
static constexpr uint32_t NUDGE_DIR_SETTLE_US = 50;

static constexpr uint32_t CAL_FAST_RPM   = 60;   // was 120 with 2 mm/rev; same linear speed with 4 mm/rev
static constexpr uint32_t CAL_SLOW_RPM   = 10;   // was 20 with 2 mm/rev; same linear speed with 4 mm/rev
static constexpr uint32_t CAL_CENTER_RPM = 20;   // was 40 with 2 mm/rev; same linear speed with 4 mm/rev
static constexpr uint32_t JOG_RPM        = 12;   // approx old 25 rpm linear jog speed

static constexpr uint32_t DEFAULT_RPM     = 500;
static constexpr uint32_t START_FLOOR_RPM = 30;
static constexpr uint32_t DEFAULT_RAMP    = 75;
static constexpr uint32_t MIN_RAMP_RPM_S  = 5;
static constexpr float    STOP_RPM_EPS    = 0.50f;

static constexpr int32_t DEFAULT_SPACE_UM    = 1000;  // 1.000 mm per turn (confirmed)
static constexpr int32_t DEFAULT_SOFTDIST_UM = 500;   // 0.500 mm
static constexpr uint8_t DEFAULT_SOFTPCT     = 40;

static constexpr uint8_t  DEFAULT_CHAOS_PCT           = 19;
static constexpr bool     DEFAULT_CHAOS_ENABLE        = true;
static constexpr uint16_t DEFAULT_CHAOS_PERSIST_TURNS = 17;

static constexpr int32_t  CAL_BACKOFF_UM = 5500;
static constexpr uint32_t AUTO_RECAL_INTERVAL_TURNS = 2000;

// -----------------------------------------------------------------------------
// Default calibration profile (values from the reference machine - replace with
// the DEF_*_INSET_STEPS that stat prints after a manual cal on your machine)
//
// Meaning:
//   Find hard limits first, then rebuild working window relative to those limits.
//   TOP soft/work bound    = hardTop    - topInsetSteps
//   BOTTOM soft/work bound = hardBottom + bottomInsetSteps
//   The defcal banner is printed from these constants, so it always matches.
// -----------------------------------------------------------------------------
static constexpr int32_t DEFAULT_PROFILE_TOP_INSET_STEPS    = 1621;
static constexpr int32_t DEFAULT_PROFILE_BOTTOM_INSET_STEPS = 214;
static constexpr int32_t DEFAULT_CAL_OFFTOP_UM              = 3250;
static constexpr int32_t DEFAULT_CAL_OFFBOTTOM_UM           = 0;
static constexpr int32_t DEFAULT_PROFILE_SOFTDIST_UM        = 500;
static constexpr uint8_t DEFAULT_PROFILE_SOFTPCT            = 40;
static constexpr bool    DEFAULT_PROFILE_CHAOS_ENABLE       = true;
static constexpr uint8_t DEFAULT_PROFILE_CHAOS_PCT          = DEFAULT_CHAOS_PCT;

// -----------------------------------------------------------------------------
// Enums
// -----------------------------------------------------------------------------
enum class MachineState : uint8_t {
  IDLE = 0,
  CAL_FIND_LIMITS,
  CAL_JOG,
  READY,
  RUNNING_AUTO,
  RUNNING_SPIN,
  PAUSED_AUTO,
  TAP_PAUSE,
  FAULT_FAILSAFE,
  FAULT_SNAG,
  FAULT_TENSION,
  TERMINATED
};

enum class TraverseDir : int8_t {
  TO_BOTTOM = -1,
  TO_TOP    = 1
};

enum class CalMode : uint8_t {
  MANUAL = 0,
  PROFILE_TEMPLATE,
  AUTO_RECAL
};

enum class CalFindSubstate : uint8_t {
  GO_BOTTOM_FAST = 0,
  BACKOFF_BOTTOM,
  GO_BOTTOM_SLOW,
  CLEAR_BOTTOM_AFTER_SLOW,
  GO_TOP_FAST,
  BACKOFF_TOP,
  GO_TOP_SLOW,
  CLEAR_TOP_AFTER_SLOW,
  GO_CENTER,
  RESTORE_PROGRESS,
  DONE
};

enum class StartPhase : uint8_t {
  NONE = 0,
  MOVE_TO_EFFECTIVE_BOTTOM
};

// -----------------------------------------------------------------------------
// Data
// -----------------------------------------------------------------------------
struct Config {
  bool     winderCW = true;
  uint32_t rpm = DEFAULT_RPM;
  uint32_t rampRPMperSec = DEFAULT_RAMP;
  uint32_t totalTurns = 10000;
  int32_t  space_um = DEFAULT_SPACE_UM;

  int32_t  offTop_um = 0;
  int32_t  offBottom_um = 0;

  int32_t  softDist_um = DEFAULT_SOFTDIST_UM;
  uint8_t  softPct = DEFAULT_SOFTPCT;

  bool     chaosEnable = DEFAULT_CHAOS_ENABLE;
  uint8_t  chaosPct = DEFAULT_CHAOS_PCT;
  uint16_t chaosPersistTurns = DEFAULT_CHAOS_PERSIST_TURNS;

  uint8_t  tapCount = 0;
  uint32_t tapTargets[3] = {0, 0, 0};

  // Drift compensation: driftCompSteps of traverse-counter correction are spread
  // evenly over every driftCompTurns turns while winding. Positive = the wind was
  // drifting toward TOP (the counter fell behind the carriage). 0 turns = off.
  int32_t  driftCompSteps = 0;
  uint32_t driftCompTurns = 0;
};

struct SetupFlags {
  bool haveDir   = false;
  bool haveRPM   = false;
  bool haveTurns = false;
  bool haveSpace = false;
};

struct Calibration {
  bool hardValid = false;
  bool softValid = false;

  bool softTopSaved = false;
  bool softBottomSaved = false;

  int32_t hardTopSteps = 0;
  int32_t hardBottomSteps = 0;

  int32_t softTopSteps = 0;
  int32_t softBottomSteps = 0;
};

struct RuntimeData {
  int32_t effectiveTopSteps = 0;
  int32_t effectiveBottomSteps = 0;

  TraverseDir traverseDir = TraverseDir::TO_TOP;

  uint32_t turnsDone = 0;
  uint32_t stepInTurn = 0;

  int64_t traverseDemandNumer = 0;
  int32_t travelSinceReverse_um = DEFAULT_SOFTDIST_UM;

  bool stopRequested = false;
  bool pauseRequested = false;
  bool autoStartPending = false;

  uint32_t spinRPM = 0;
  bool spinCW = true;

  bool midActive = false;
  int32_t midInset_um = 0;
  uint32_t midTurnsRemaining = 0;

  bool midArmed = false;
  int32_t midArmedInset_um = 0;
  uint32_t midArmedTurns = 0;

  int8_t activeTapIndex = -1;
  bool tapTriggered[3] = {false, false, false};

  bool autoRecalPending = false;
  uint32_t nextAutoRecalTurn = AUTO_RECAL_INTERVAL_TURNS;

  int32_t chaosSpaceOffset_um = 0;
  uint16_t chaosTurnsRemaining = 0;

  int32_t driftCompAccum = 0;   // fractional driftcomp remainder, in "steps x turns"
};

struct LiveStatus {
  MachineState state = MachineState::IDLE;
  bool permitOK = true;
  bool snagOK = true;
  bool topLimit = false;
  bool bottomLimit = false;
  uint32_t currentRPM = 0;
};

struct RecalSnapshot {
  bool valid = false;

  uint32_t turnsDone = 0;
  uint32_t stepInTurn = 0;
  TraverseDir traverseDir = TraverseDir::TO_TOP;

  bool tapTriggered[3] = {false, false, false};
  int8_t activeTapIndex = -1;
  uint32_t nextAutoRecalTurn = AUTO_RECAL_INTERVAL_TURNS;

  float relativePos = 0.0f;
  int32_t topInsetSteps = 0;
  int32_t bottomInsetSteps = 0;

  // Where the hard switches were found at the PREVIOUS calibration, in the same
  // continuous step frame, so the re-found positions reveal the accumulated drift.
  int32_t oldHardTopSteps = 0;
  int32_t oldHardBottomSteps = 0;
  uint32_t turnMark = 0;
};

struct CalProfile {
  bool valid = false;
  int32_t topInsetSteps = 0;
  int32_t bottomInsetSteps = 0;
  int32_t offTop_um = 0;
  int32_t offBottom_um = 0;
  int32_t softDist_um = DEFAULT_SOFTDIST_UM;
  uint8_t softPct = DEFAULT_SOFTPCT;
  bool chaosEnable = DEFAULT_CHAOS_ENABLE;
  uint8_t chaosPct = DEFAULT_CHAOS_PCT;
};

struct ChaosEntropyInfo {
  uint32_t seedMicros = 0;
  uint32_t seedMillis = 0;
  uint32_t seedAddr = 0;
  uint32_t mixHistory[8] = {0};
  uint32_t finalSeed = 0;
  uint32_t reseedCount = 0;
};
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
void loop() {
  wdtFeed();
  refreshInputs();
  handleFaults();
  updateTension();

  uint32_t nowUs = micros();

  if (st.state == MachineState::RUNNING_AUTO ||
      st.state == MachineState::RUNNING_SPIN) {
    updateWinderRamp();
  }

  bool winderStepped = winder.update(nowUs);
  (void)traverse.update(nowUs);

  if (winderStepped && st.state == MachineState::RUNNING_AUTO) {
    handleWinderStepEvents();
  }

  if (st.state == MachineState::CAL_FIND_LIMITS) {
    updateCalibrationFind();
  }

  // CAL_JOG runs the traverse continuously with nothing else watching the
  // limits; stop it before it drives the carriage into the hard stop.
  if (st.state == MachineState::CAL_JOG && jogDir != 0) {
    if ((jogDir > 0 && topLimitTriggered()) || (jogDir < 0 && bottomLimitTriggered())) {
      stopTraverse();
      jogDir = 0;
      Serial.println("OK jog stopped at limit switch");
    }
  }

  if (st.state == MachineState::READY && rt.autoStartPending) {
    handleStartMoveToBottom();
  }

  handleStoppedAutoTransitions();

  if (st.state == MachineState::RUNNING_AUTO && statusTimer >= STATUS_INTERVAL_MS) {
    printRunStatusLine();
    statusTimer = 0;
  }

  serviceUsbCommandPort(Serial, rxLine);
}

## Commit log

2026-09-27 Open Winder public release: public firmware, wiring CSV, STL files
    [Bottom Clamp.step, Bottom Limit Housing.step, Bottom_Clamp_1.stl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]
2026-10-11 Firmware: traverse lead screw 5 mm/rev (public release r2)
    The reference machine's traverse lead screw is 5 mm/rev. The sketch
    assumed 4 mm, so every traverse distance typed in mm moved the carriage
    1.25x what it said (space 1.0 actually wound at 1.25 mm/turn).
    - TRAV_LEAD_UM_PER_REV 4000 -> 5000. Traverse drive stays at 400
    steps/rev (no DIP change); one step is now 12.5 um.
    - Step <-> distance math now runs in nanometres (TRAV_STEP_NM) so a
    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
2026-10-11 Docs: add Open Winder Build & Wiring Guide
    New docs/build-guide.md for anyone building an Open Winder from this repo:
    parts list with each component's job, power wiring, the full Teensy 4.1
    pin map, terminal-by-terminal drive and motor wiring, DM542T DIP switch
    settings, limit switch and load-cell wiring, optional firmware-supported
    inputs, firmware setup, first power-up checks, calibration (and where
    the stat values go in the sketch), the full command reference, worked
    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
2026-10-13 Add Amazon parts links and affiliate disclosure
    Parts list in README, linked sources in the BOM, and a where-to-buy
    note in the build guide.
    Claude-Session: https://claude.ai/code/session_01CmhdmPbfHzDssF6xq6ramk
